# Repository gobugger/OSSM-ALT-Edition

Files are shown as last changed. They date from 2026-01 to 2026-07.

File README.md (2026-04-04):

# OSSM ALT Edition
---
## 🎯 Overview

OSSM ALT Edition is a community-driven alternative version of the well-known [OSSM](https://github.com/KinkyMakers/OSSM-hardware) platform. A lot of time and effort has gone into this project. This has been possible thanks to all the previous work that has been done and several community members that helped test this. Do note that we are still in 'beta testing' phase and that you may run into issues. Please provide feedback to help improve the project. This project represents a ground-up redesign focused on:

- **Modern Power Delivery**: Custom 28V 140W USB-C PCB with comprehensive protection circuits
- **Simplified Assembly**: All-in-one clean design with easily sourceable components
- **European Sourcing**: BOM optimized for availability in Europe
- **Enhanced Performance**: Support for MGN12H and MGN15H rails with support for belts up to 15mm belt.
- **Open Source**: Fully open hardware

***Links***: KM [Discord community](https://kinkymakers.com) & [Ko-Fi](https://ko-fi.com/dododesigns) (for contributions / buying boards)

MGN15H version with new clamp

<sub>**Notice**: This version was developed without any involvement of the original OSSM / Research and Desire members. However, none of this would have been possible without their prior work which is greatly appreciated. Especially the work of [ArmpitMFG](https://github.com/armpitMFG) has been a great inspiration. </sub>

---

## ✨ Key Features

### Hardware Improvements
- **Custom 28V USB-C PCB** with extensive protection circuits
  - Over/under voltage protection
  - Reverse current protection
  - ESD protection on all exposed ports
  - Inrush current limiting
  - Hybrid polymer capacitors for stable power
  - Brake Chopper Add-On 360Watt
- **Dual Rail Options**
  - MGN15H for heavy-duty applications (up to 15mm belts)
  - MGN12H for lighter builds (up to 12mm belts)
- **Efficient Travel**: Rail length minus 150mm usable stroke
- **Compatible with Pitclamp Mini** and includes optimized alternative design with dowels

### Electronics & Firmware
- **ESP32-S3** microcontroller with integrated RS485 controller
- **WS2812 Status LED** (firmware support pending)
- **Made for [OSSM Rust](https://github.com/orange-gem/ossm-rs)** firmware
- Compatible with step/dir control for original firmware adaptation
- **Optional Brake Chopper PCB** for enhanced safety

### Design Philosophy
- Optimized for 3D printing (minimal supports required)
- Common, easily sourceable components
- Clean, simple assembly
- Comprehensive protection systems

---
  
## 📦 Bill of Materials

A comprehensive BOM with descriptions and links can be found [here](Assembly-Info/BOM-OSSM-ALT.csv). However, the parts below are a quick summary everything you need for building this complete version:

| **Part** | **Description** | **Costs** |
| --- | --- | ----- |
| 57AIM30 | Motor | €110  |
| MGN15H Rail | Rail 40cm | €25 |
| Or MGN12H Rail | Rail 40cm | €21 |
| 625RS Bearing  | Belt Bearings | €15 |
| M5 Bolts | Complete kit | €12 |
| M3 Bolts | Complete kit | €12 |
| Dowel Pins | Precision pins | €10 |
| GT2 Belt | 50cm | €15 |
| GT2 20T pulley | 15mm | €10 | 
| Filament  | Max 500g | €20 |
| OSSM ALT 28V PCB | Designs available for self-sourcing or buy through me to support this project. | €40 |
| **Total** | Rough approximation. Check BOM for details. | €270  |

📋 **[Complete BOM with part numbers and links](Assembly-Info/BOM-OSSM-ALT.csv)**

> **Note**: You will also need a remote control device. Compatible options include:
> - Official R&D remote
> - iOS/Android apps
> - Web control interface
> - M5 Remote (check firmware compatibility)

---

## 3D Printing Tips

500 grams of filament should be enough to complete the whole build including the main pitclamp (350 without). It is optimized as much as possible for 3D printing with only 1 part requiring a small amount of supports. The filament type should not matter for most standard build, but heavy users might want to rely on something sturdier like tough-PLA, PET-G, ASA or PC. The test builds have been printed with standard Bambulab basic PLA (Not matte/silk). 

**Filament Required**: ~500g for complete build including Pitclamp

**Recommended Materials**:
- **Standard Use**: PLA, PLA+
- **Heavy Use**: Tough-PLA, PETG, ASA, PC

**Important**: Follow the [detailed 3D printing guide](Assembly-Info/Print-Manual/README.md) carefully to ensure proper fit and function.

**Print Options**:
- Standard version (no branding)
- Multi-color branded version (AMS/toolchanger compatible)
- Single-color embossed version

MGN12H Light version

---
## Assembly:

📺 **Video Assembly Guides**:
- [Part 1](https://youtu.be/EqzNXQzpHu0) 
- [Part 2](https://youtu.be/FnY4Sz64H2A) 

📖 **Written Assembly Guide**: In development

💬 **Need Help?** Join the KM [Discord community](https://kinkymakers.com) for assembly support and questions (Look for the OSSM ALT Project).

---

## 🔌 Main PCB Specifications

Most work has gone into this PCB. My vision for this Machine/PCB is that groups of people will self-source this PCB. From 10+ pieces this makes sense, so as long as you can find 10 people you should be able to buy this at an affordable price. The rest of the machine can be printed and uses off the shelf parts. I will also sell these boards for people that only need 1 PCB and want to help support this project (please not that a lot of my own money has gone into this and any support is greatly appreciated ([Ko-Fi](https://ko-fi.com/dododesigns))

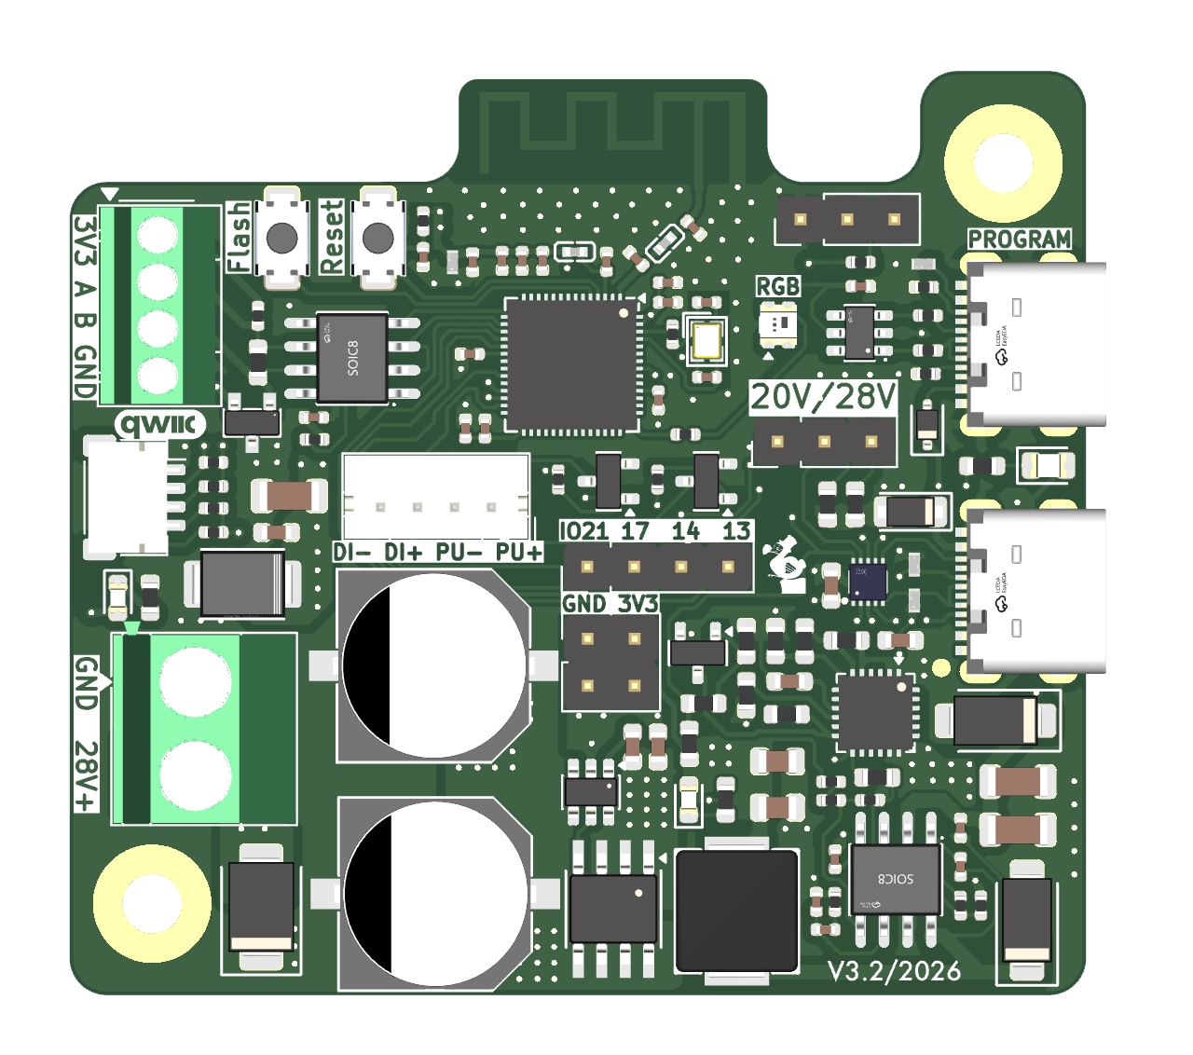
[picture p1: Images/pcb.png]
28V PCB


### Technical Features

- **Power**: CH224Q for 28V USB-C PD 3.2 negotiation
- - Continuous 140Watt capable with 4 layer optimized PCB design (load tested)
- **Controller**: ESP32-S3 microcontroller with onboard antenna
- **Communication**: Integrated RS485 controller
- **Power Protection**:
  - Hybrid polymer capacitors
  - Inrush current limiting
  - Over/under voltage protection
  - Reverse current protection
- **Additional Features**:
  - Dedicated USB-C debugging port
  - ESD protection on all exposed ports
  - WS2812 status LED
  - Brake chopper expansion support

**Design Tool**: KiCAD 9  
**Manufacturing**: Optimized for major PCB fabrication houses

### Optional Brake Chopper Add-on

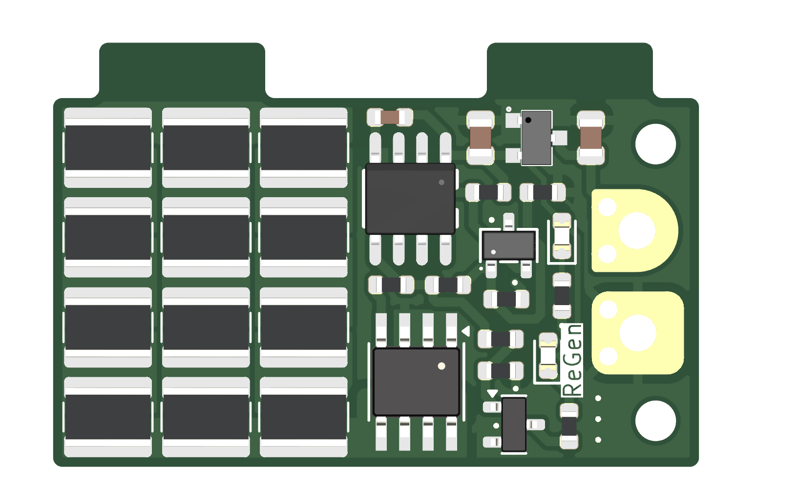
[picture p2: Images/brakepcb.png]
Brake PCB


Enhanced protection for heavy-duty use:
- **Dissipation**: 12W continuous, 360W short-term spikes
- **Protection Threshold**: 33V (protects 36V TVS diode)
- **Purpose**: Back-EMF spike suppression
- **Recommended For**: Heavy users and added safety margin

This was mainly a fun side project for me which also adds functionality. It is basically an improved version of a Pololu Shunt Regulator, but completely redesigned with an on-board gate driver, 12V LDO, and 12watts of power resistors (2 sides assembly up to 24watt). This PCB was designed to be very cheap and easy to produce. 

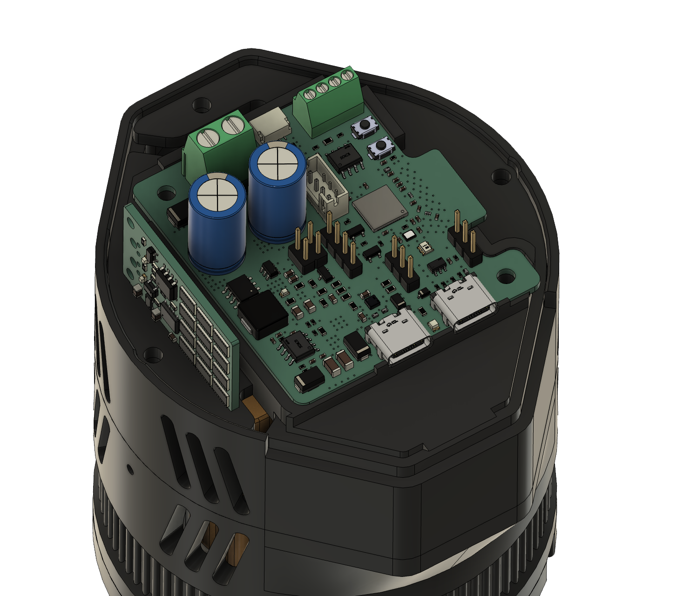
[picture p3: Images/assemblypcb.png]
Assembly PCB


---
## 🔋 Compatible Power Sources

This design is focused around PD, so it only makes sense to provide some options that are tested.

> **Important**: Use a USB-C cable with E-marker chip for >3A current. Standard cables will limit performance.

### Tested & Confirmed

| Device | Type | Rating | Status | Recommended | Rating | Notes |
|---|---|---|---|---|---|-----|
| [Apple 140W USB-C Adapter](https://www.apple.com/nl/shop/product/mw2m3zm/a/usb%E2%80%91c-lichtnetadapter-van-140-w) | Wall Adapter | 28V / 5A (140W) | 🔬 Tested | ✅ Recommended| ★★★★★ (5)| Excellent reliability and quality, Only ~€60 (will likely not work with other pcb's besides the OSSM ALT since it requires inrush current protection) |
| [Ugreen 200W Powerbank](https://eu.ugreen.com/products/ugreen-nexode-power-bank-200w-25000mah) | Powerbank | 28V / 5A (140W) | 🔬 Tested| ✅ Recommended|★★★★★ (5)| Great portable option that negotiates with almost any chip. Best power bank I have tested.|
| [Anker 140W Wall Adapter](https://www.anker.com/products/a2697-anker-charger-140w-4-port) | Wall Adapter | 28V / 5A (140W) | 🔬 Tested| ✅ Recommended|★★★★☆ (4)| Works well, but you will definitely feel it get hot at prolonged 140W and after 20 minutes or so it will lower the power to cool down. 100Watts continuous is fine so for the gold motor there are no problems. I have yet to see a supported motor that pulls 140W continuous. 
| [Sitecom 140W Wall adapter](https://www.action.com/nl-nl/p/3221194/sitecom-usb-wandoplader/) | Wall Adapter | 28V / 5A (140W)|🔬 Tested | ✅ Recommended| ★★★★☆ (4) | Cheapest adapter of the list (~€20). Did not do any extensive testing yet, but it negotiates 28V and 20V fine. I was also able to load test it at 140W and you can feel it get warmer similar to the Anker one, but it seems to hold up fine. At it's price point it is probably a very good deal (even comes with a cable), but we don't know if it's easy to source since right now it's sold at 'action' which normally changes its inventory quite quickly. 
| [Ugreen 100W Wall Adapter](https://www.amazon.nl/dp/B091TV6LWN) | Wall Adapter | 20V / 5A (100W) | 🔬 Tested | ⚠️ Lower Power|★★★☆☆ (3) |Works okay, but do notice that this one does not support 28V. If you have the OSSM-Alt pcb at 28V and still try to power it, it will work but negotiates down to 20V. |
| [Framework 180W Adapter](https://frame.work/nl/en/products/16-power-adapter?v=FRANCR000F) | Wall Adapter | 36V / 5A (180W) | 🔬 Tested | ⚠️ Lower Power | ★★★☆☆ (3) | Quality wise I believe this is a good adapter, but it has a lot of difficulty negotiating with several common cheap PD chips. So it won't negotiate above 20V on the OSSM-ALT PCB and it also does not seem to support I2C with this chip either. Therefore, not really recommended unless you already have it and just power a motor at max 100W. 
| Apple 67W Adapter | Powerbank | 20V / 3.3A (67W) | 🔬 Tested | ⚠️ Lower Power | ★★☆☆☆ (2.5) | Negotiates well and also supports I2C negotiation. 67W is however on the lower side, so this is definitely not recommended for heavy usage. Still, this was the adapter I first tested my OSSM with and from my experience 67W is enough for most light play.  |
| Xiaomi Mi 50W | Powerbank | 20V / 2A (40W) | 🔬 Tested | ⚠️ Low Power | ★★☆☆☆ (2) | Not recommended. Negotiates well, but low power. Still for a very light weight OSSM it might. be fine.  |

**Have you tested another power source?** Please share your results!

---

## ❤️ Support the Project

If you've built an OSSM ALT and want to support continued development:

### Financial Support

- **PCB Purchase**: Buy boards from me to support the project (Discord PM, Ko-Fi (soon))
- **Buy a hardware kit**: If there is enough demand, I might start selling some hardware kits 
- **Donations**: [Ko-Fi](https://ko-fi.com/dododesigns) *(or contact me on Discord)*

### Non-Financial Support

- ⭐ **Star this repository** to increase visibility
- 📢 **Share the project** with your community
- 📸 **Share your build** with photos and feedback on Discord
- 📖 **Contribute documentation** and improvements

teaser

---

## 📜 License

This project is **Open Source Hardware**.

All hardware design files (including PCB schematics, layouts, and 3D mechanical design files) are licensed under the **CERN Open Hardware Licence Version 2 – Strongly Reciprocal (CERN-OHL-S-2.0)**.

You are free to:
- Use, study, modify, and manufacture this design

Under the following conditions:
- **Attribution** must be given to the original author(s)
- **All modified versions and derivatives must be released under the same license**
- **Complete corresponding source files must be made available**

---

## 🙏 Acknowledgments

Special thanks to:

### Core Contributors
- **OrangeMurker & Nakata** - OSSM Rust firmware development and invaluable feedback
- **Beta Testers** - All community members who tested and provided feedback

### Inspiration & Prior Art
- **[armpitMFG](https://github.com/armpitMFG)** - Front/end effector designs and Pitclamp Mini
- **Original OSSM / R&D Team** - Foundation and inspiration for this project

### Community
- All contributors who have improved this design
- Discord community members providing support and feedback

---

## ⚠️ Disclaimer

This project is currently in **beta testing phase**. While extensively tested, you may encounter issues. Please provide feedback to help improve the project.

**Safety**: This is a DIY project involving motors and electronics. Build and use at your own risk. Ensure all safety precautions are followed during assembly and operation.

---

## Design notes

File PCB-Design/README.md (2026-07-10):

# PCB Design

This folder contains everything related to the two PCBs of the OSSM ALT Edition (the main PCB and the brake chopper), organized as follows:

| Folder | Contents |
| --- | --- |
| [Schematic and Design](Schematic%20and%20Design/) | The schematics of both PCBs and their STEP files |
| [Production Files](Production%20Files/) | A manual on ordering, plus all the files needed to produce the PCBs yourself (Gerbers, BOM, CPL) |
| [Kicad Files](Kicad%20Files/) | The KiCad project files, if you wish to edit things |

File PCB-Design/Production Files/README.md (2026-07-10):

# Production Files

This folder contains everything you need to order the PCBs and cables for the OSSM ALT Edition. There are **two separate boards** plus the **cables**:

| Item | Location | Status |
| ---- | --- | --- |
| **Main PCB** (OSSM ALT Servo) | [Main-PCB](Main-PCB/) | ✅ Production ready |
| **Brake Chopper** (optional add-on) | [Brakechopper](Brakechopper/) | ✅ Production ready |
| **Cables** (power & RS485) | [Cable Sourcing](#-cable-sourcing) (below) | ✅ Production ready |

Each version folder contains the Gerber files (zip), BOM and CPL (component placement) files, ready for upload.

---

## 🟢 Main PCB

The main PCB is best ordered from **[JLCPCB](https://jlcpcb.com)**. All components have been selected based on availability from LCSC and compatibility with JLCPCB's **Economic Assembly** service, which saves quite a bit on setup costs compared to Standard assembly.

### PCB Specifications

These are basically the default JLCPCB settings for a 4-layer board, to keep ordering easy. They are written out here in case you use another PCB supplier:

| Setting | Value |
| --- | ----- |
| Layers | 4 |
| Thickness | 1.6mm |
| Material | Standard FR4, **TG135** |
| Stackup | "No requirement" — currently **JLC04161H-7628** (the default for 4-layer 1.6mm) |
| Outer copper | 1oz |
| Inner copper | 0.5oz |
| Surface finish | HASL — ENIG is nicer/better, but on a 4-layer board it is not supported with Economic Assembly, only Standard |

> ⚠️ **Important**: The material and stackup matter for impedance matching. The WiFi antenna is calculated based on the JLC04161H-7628 stackup (the one JLCPCB selects by default when you choose "no requirement" on a 4-layer 1.6mm board). If you order elsewhere, match this stackup as closely as possible.

### Assembly Settings

- Select **PCB Assembly**, **top side** only.
- Choose the **Economic** assembly type. All parts have been sourced to be compatible with it.

> 💡 **Tip — parts out of stock?** The hard part of ordering via Economic Assembly is that not all parts are always in stock. Have a look at JLCPCB's **Part Sourcing** section on their website: you can pre-order parts beforehand at very affordable prices and build your own personal inventory. Once everything is in your personal stock, you can place the assembly order.

### Parts You Solder Yourself

To save costs, the through-hole headers and the back-emf capacitors are **not** pre-soldered. These are easy through-hole parts you can solder at home:

| Qty | Part | LCSC # | Purpose |
| --- | ---- | --- | --- |
| 2 | 1x3 pin header, 2.54mm | [C32713269](https://jlcpcb.com/partdetail/C32713269) | Voltage selection & IO |
| 1 | 2.54mm jumper | [C20417895](https://jlcpcb.com/partdetail/C20417895) | Voltage selection (20V/28V) |
| 1 | JST PH 1x4 connector | [C131334](https://jlcpcb.com/partdetail/C131334) | RS485 cable connection |
| 1 | *(alternative)* 4-position 2.54mm terminal connector | [C918122](https://jlcpcb.com/partdetail/C918122) | Use instead of the JST PH if you don't want to crimp a custom cable |
| 1 | 2-position 5.08mm power terminal | [C8465](https://jlcpcb.com/partdetail/C8465) | 28V power input |
| 2 | 470µF 50V hybrid polymer capacitor | [C53237827](https://jlcpcb.com/partdetail/C53237827) | Catches back-EMF spikes |

### About the Capacitors (Back-EMF)

The two 470µF 50V hybrid polymer capacitors are **very important if you don't use a brake chopper** — they catch the back-EMF spikes from the motor. With the brake chopper installed you could get away with a smaller SMD variant.

You can also choose 35V versions, which are available at 1000µF each (2000µF total). For smaller/regular sized toys this would be safe enough to run without a brake chopper. **However**, under heavy usage with very fast back pressure, the voltage can rise to around **43V** with 1000µF of capacitance — above the 35V rating. With 2000µF it would stay lower, but this is **not recommended and not tested**. When in doubt, stick with the 50V parts.

### Polarity Checks (Important!)

JLCPCB will probably send you an email asking to **confirm the orientation of the WS2812 RGB LED** — for some reason they keep doing that with this specific part. Just confirm the polarity matches the image below and continue:

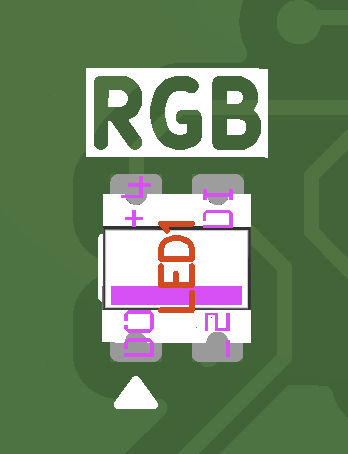
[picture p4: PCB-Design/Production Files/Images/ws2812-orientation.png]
WS2812 orientation


Also check all other polarities (diodes, polarized capacitors). If you use the **provided CPL file, it should be fine** — but a fresh export from KiCad will probably *not* have the right rotations, and you will need to check them yourself. Use this overview of the fully placed top side as reference:

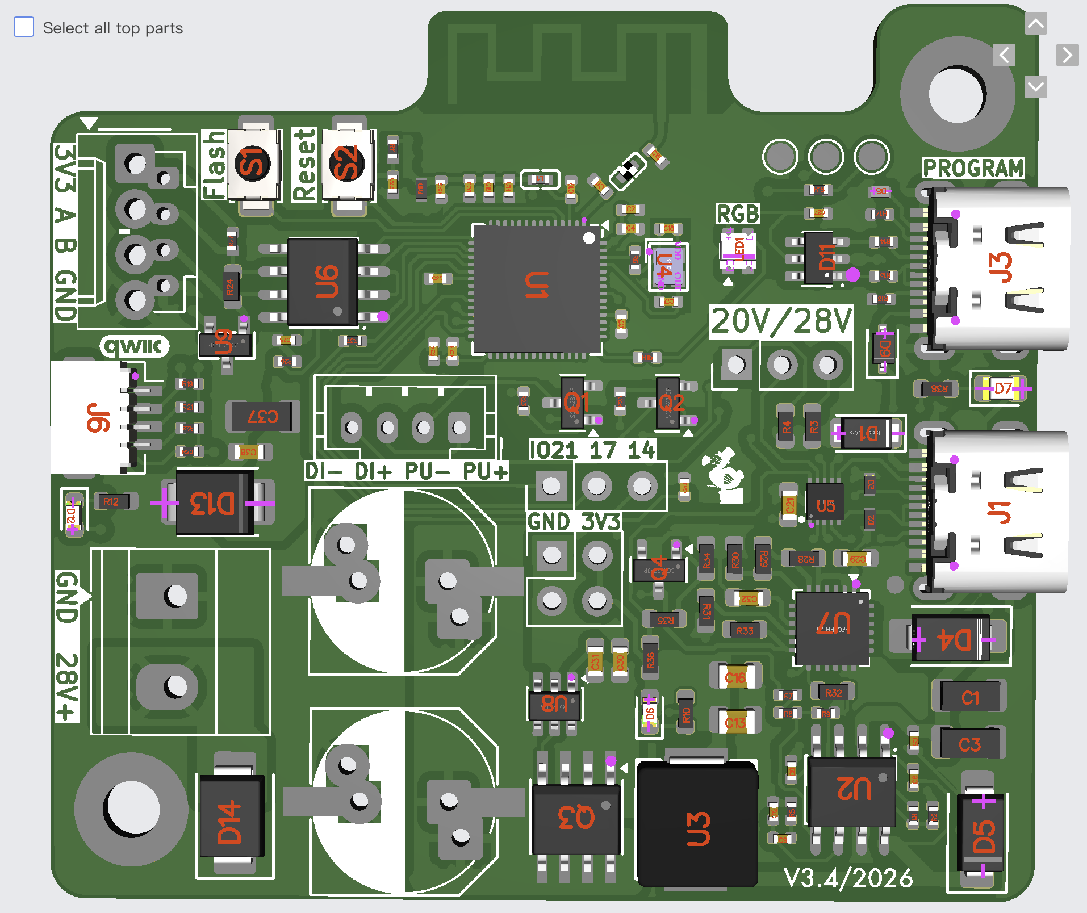
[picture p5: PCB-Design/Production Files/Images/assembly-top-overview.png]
Top side assembly overview


---

## 🟡 Brake Chopper

The brake chopper is an optional add-on designed as **extra protection for the main PCB**. It catches the voltage spikes from the motor that happen when the motor rapidly decelerates, changes direction, or is pushed back. This has been thoroughly tested: it stops all spikes over **33V**, which then get dumped into the 1218 resistor bank.

The production files can be found in [Brakechopper/v1_1](Brakechopper/v1_1/).

### PCB Specifications

| Setting | Value |
| --- | ----- |
| Layers | 2 |
| Copper | 1oz |
| Surface finish | ENIG or HASL (both will work) |

### Single or Double Sided Assembly

You can choose to have this board assembled **one sided or double sided** — both will work, but the power dissipation rating of the resistor bank differs:

| Assembly | Resistors | Power dissipation rating |
| --- | --- | --- |
| Double sided | 24 | 24W |
| Single sided | 12 | 12W |

> **Note**: this is *not* a continuous rating — the board is not designed to draw power continuously. It only dissipates the short braking spikes.

It's a clean design that you should be able to source at very low cost: the first single-sided version came out at roughly €1.50 each assembled, and the double-sided version at around €5. Both will probably be pricier at lower quantities.

### Sourcing the Resistors (the hard part)

The tricky part is sourcing the resistors in larger quantities: 10 boards is already 240 resistors, and 100 boards means finding 2400 of them. JLCPCB can ask extreme prices for ordering these reels, so it makes more sense to **pick a resistor value that is in stock / affordable to source** rather than insisting on one exact value.

The reference design uses **4.7Ω** resistors. On the double-sided board the bank is wired as: top+bottom pairs in parallel (4.7Ω / 2 = 2.35Ω), 4 of those in series (9.4Ω), and 3 of those columns in parallel — giving a total resistance of:

```
(4.7Ω / 2) × 4 / 3 ≈ 3.13Ω
```

At the 33V clamping point that dissipates **P = V² / R = 33² / 3.13 ≈ 348W** (about 10.5A) during a braking event.

For a **single-sided** board there are no parallel pairs, so the total is simply `value × 4 / 3`. With only 12 resistors, a value of around **2.4Ω** makes more sense:

```
2.4Ω × 4 / 3 = 3.2Ω  →  33² / 3.2 ≈ 340W
```

> ⚠️ **Rule of thumb**: aim for roughly **3.1–3.2Ω total resistance (~350W dissipation)**. I would not go higher than this — a too high total resistance lowers the spikes the board can catch which means that these spikes then still go to the main board.

### Status LEDs

The board has two LEDs:

- 🟠 **Orange** — the board has power.
- 🔴 **Red** — the voltage has risen above 33V and the brake chopper is actively dumping into the resistor bank.

### Polarity Checks

Just like the main PCB: check the component polarities against the provided images before confirming the order.

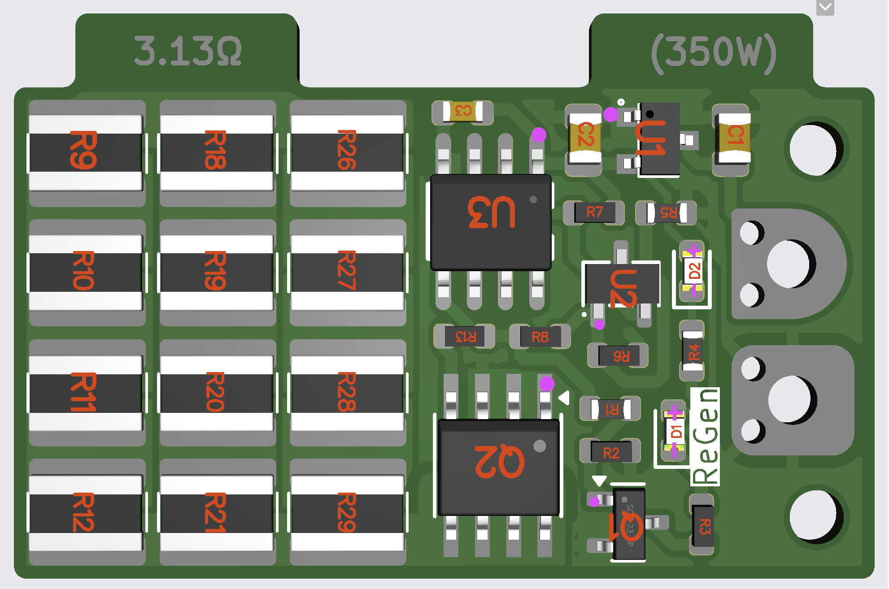
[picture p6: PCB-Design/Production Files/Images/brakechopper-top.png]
Brake chopper top side


---

## 🔌 Cable Sourcing

### Main Power

For the main power supply to the board I use **18 AWG silicone cables**. These silicone cables are nice and flexible and can easily handle the currents.

### RS485 Cable

For the RS485 connection between the board and the motor there are two options:

1. **Terminal block** — use the 4-position terminal connector ([C918122](https://jlcpcb.com/partdetail/C918122), see the main PCB parts table), cut the connector off one side of the cable that came with the motor, and hook it up that way.
2. **Custom RS485 cable** — this is what the boards I sold use. It's more foolproof and easier to assemble/disassemble.

For the custom cable I used **LCSC's cable assembly service**. To give an idea of pricing: 50 pieces cost around **€85 including shipping** — it probably makes more sense at higher quantities. At lower quantities you should be able to crimp them yourself with the parts below.

The cable specs: roughly **70mm long**, **24 AWG silicone wire**, with the data pair twisted (**~6 twists**). Twisting shouldn't be necessary at this short length, but it's basically free when ordering through LCSC.

> **Note**: I can't share the original manufacturer drawing (I don't hold the copyright), so the drawing below is a recreation with the same information.

RS485 cable drawing

Wiring table (also shown in the drawing — the used pins are colored in the P1 mating face view):

| Wire | P1 pin | P2 pin |
| ----- | --- | --- |
| Green | 7 | 2 |
| Blue | 8 | 3 |
| Red | 5 | 1 |
| Black | 1 | 4 |

The numbered callouts in the drawing match this parts list:

| # | Part | Qty | Description | LCSC # |
| - | ---- | --- | --- | --- |
| 1 | Wire | 4 | UL1007 24 AWG (red / blue / green / black), L = 70mm | — |
| 2 | Housing | 1 | 2.0mm pitch, 2×5 positions, white — Megastar ZX-PHB2.0-2-5PJK | [C19078773](https://www.lcsc.com/product-detail/C19078773.html) |
| 3 | Terminal | 4 | Tin plated, 24–28 AWG — Megastar ZX-PHB2.0-2-DZ | [C19078769](https://www.lcsc.com/product-detail/C19078769.html) |
| 4 | Housing | 1 | 2.0mm pitch, 4 positions, white — JST PHR-4 | [C111514](https://www.lcsc.com/product-detail/C111514.html) |
| 5 | Terminal | 4 | Tin plated, 22–26 AWG — JST SPH-001T-P0.5S | [C495193](https://www.lcsc.com/product-detail/C495193.html) |

To clarify, here are photos of a finished cable and close-ups of both connector ends:

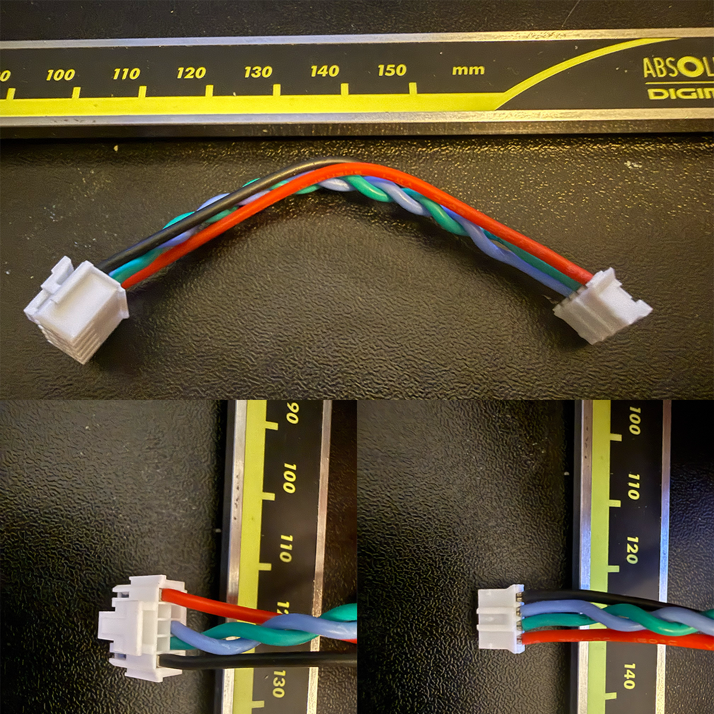
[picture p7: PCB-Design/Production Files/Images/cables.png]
Finished RS485 cable


---

## ⚠️ Disclaimer

No warranties are given based on the information in this document. Ordering PCBs and cables is always a risk, and I take no responsibility for the correctness of this information. Previous experience with ordering PCB assembly definitely helps — these are not the easiest boards.

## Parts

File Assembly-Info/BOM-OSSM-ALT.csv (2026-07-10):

Assembly Category,Item No.,Part Name,Description,Quantity,Unit,Supplier Link,Unit Price,Total Price,Remarks
"Belt Mechanics,B-0,MGN-15H Rail,""Tested with 400mm Length"",1,pcs,,,,""The better the quality, the smoother it will be. Legitimate Hiwin is preferred, but Aliexpress alternatives will probably work as well. Usable length is approximately rail length - 150mm"""
"Belt Mechanics,B-1,625-RS Bearings,Belt Bearings,6,pcs,https://www.amazon.nl/dp/B071RXC7FV?,€8.99,€8.99,""10 Pack"""
"Belt Mechanics,B-2,Precision Dowel Pin Kit,Dowel Pins for Bearings Kit,1,pcs,https://www.amazon.nl/dp/B0DR7R87KQ?th=1,€12.99,€12.99,""This pack contains all the pins needed for the complete OSSM ALT version including new Pit Clamp"""
"Belt Mechanics,B-2B,M5*30 Dowel Pin (2 pins),M5*30 dowel 5 pack,1,pcs,https://eu.store.bambulab.com/nl/products/d5-stainless-steel-dowel-pin?id=48706172092764,€1.45,€1.45,""This is sufficient if you are only making the belt mechanics without redesigned pitclamp. You do not need the dowel pin kit in this case"""
"Belt Mechanics,B-3,GT2 Belt (9-12 or 15mm),""Rail length + 10cm"",,,,,,""Pick any GT2 belt that will fit your GT2 pulley. OSSM ALT version supports everything up to 15mm. 15mm gives the most grip"""
"Belt Mechanics,B-4,GT2 20T Pulley (15mm belt max),Pulley for your belt size,1,pcs,,,,""Pick a pulley that fits your belt. A pulley that supports a 15mm belt has maximum performance, but 9 or 12mm will work as well"""
"Belt Mechanics,B-5,M5 Bolt Kit,M5 bolt kit for complete OSSM ALT,1,pcs,https://www.amazon.nl/dp/B0DPWYNDZF?,€11.99,€11.99,""This kit contains all the M5 bolts that are needed for the complete OSSM Alt Edition including redesigned Pitclamp"""
"Belt Mechanics,B-5B,M5*30 Head Cap Bolt,Front mount bolts,2,pcs,,,,""Only needed if you don't buy the M5 bolt kit"""
"Belt Mechanics,B-5C,M5*20 Head Cap Bolt,Front mount bolts,1,pcs,,,,""Only needed if you don't buy the M5 bolt kit"""
"Belt Mechanics,B-6,M3 Bolt Kit,M3 bolt kit for complete OSSM ALT,1,pcs,https://www.amazon.nl/dp/B0B3MGZ7T2,€8.88,€8.88,""This kit contains all the M3 bolts that are needed for the complete OSSM Alt Edition"""
"Motor / PCB Housing,C-0,57AIM30 motor,OSSM Motor,1pcs,,,€100,,""Around 100 euros including shipping and taxes to Europe"""
"Motor / PCB Housing,C-1,M3 Bolt Kit,M3 bolt kit for complete OSSM ALT,1,pcs,https://www.amazon.nl/dp/B0B3MGZ7T2,€8.88,€8.88,""This kit contains all the M3 bolts that are needed for the complete OSSM Alt Edition"""
"Belt Mechanics,B-6B,M3*12 Head Cap Bolt,Rail bolts,4,pcs,,,,""Only needed if you don't buy the M3 bolt kit"""
"Motor / PCB Housing,C-1B,M3*40 bolt,Housing bolts,2,pcs,,,,""Only needed if you don't buy the M3 bolt kit"""
"Motor / PCB Housing,C-1C,M3*8 bolt,PCB Mount,2,pcs,,,,""Only needed if you don't buy the M3 bolt kit"""
"Motor / PCB Housing,C-1D,M3*12 bolt,Top Cover Bolt,1,pcs,,,,""Only needed if you don't buy the M3 bolt kit"""
"Motor / PCB Housing,C-2,M5*30 bolt,Motor Fastening Bolts,4,pcs,,,,""Only needed if you don't buy the M5 bolt kit (also not needed if you are using the original OSSM belt mechanics/front)"""
"Motor / PCB Housing,C-1E,M3 nuts,Captive Nuts,5,pcs,,,,""Only needed if you don't buy the M3 bolt kit"""
"Motor / PCB Housing,C-2B,M5 nuts,Captive Nuts,3,pcs,,,,""Only needed if you don't buy the M5 bolt kit"""
"Motor / PCB Housing,C-2C,M5 Lock nuts,M5 Motor lock nuts,4,pcs,https://www.toolstation.nl/borgmoeren/p12051,€3.05,€3.05,""You can also use regular nuts, but those might vibrate. This is also needed if you are using the original OSSM. The link is for 100 pieces"""
"Motor / PCB Housing,C-3,OSSM ALT version Custom PCB,Custom PCB for the ALT Version,1,pcs,,TBD,TBD,""All production files are available. If you source them yourself and order a minimum of 10, the price should drop to around 13 euros per piece, and to 10 euros at 20+"""
"Redesigned Pitclamp,D-1,Precision Dowel Pin Kit,Dowel Pins for Bearings Kit,1,pcs,https://www.amazon.nl/dp/B0DR7R87KQ?th=1,€12.99,€12.99,""This pack contains all the pins needed for the complete OSSM ALT version including new Pit Clamp"""
"Redesigned Pitclamp,D-1B,M5*25 Dowel Pin (3 pins),M5*25 dowel 5 pack,1,pcs,https://eu.store.bambulab.com/nl/products/d5-stainless-steel-dowel-pin?id=48706172059996,€1.45,€1.45,""Only needed if you don't buy the dowel pin kit"""
"Redesigned Pitclamp,D-1B,M5*16 Dowel Pin (1 pins),M5*16 dowel 5 pack,1,pcs,https://eu.store.bambulab.com/nl/products/d5-stainless-steel-dowel-pin?id=48706171994460,€1.35,€1.35,""Only needed if you don't buy the dowel pin kit"""
"Redesigned Pitclamp,D-2,M5*20 Head Cap bolt,Bolts to mount to 3030 extrusion,2,pcs,,,,""Only needed if you don't buy the M5 bolt kit"""
"Redesigned Pitclamp,D-2,3030 extrusion M5 fastening nuts,M5 nuts for 3030 extrusion,2,pcs,,,,""Just pick what you have or what you can get. As long as it's M5 and fits 3030, it will work"""
Belt Clamp,E-1,M3 nuts,M3 nut,1,pcs,,,,
"Belt Clamp,E-2,M3*16 head cap bolt,Optional for front mount,1,pcs,,,,""Optional to make sure it stays on, but not necessary since everything is tightened together by the belt"""
"Other,F-0,3D print filament,""500g should be more than sufficient."",,,,,,""Pitclamp: 100g / Belt tensioning and toy mount: 63g / Belt mechanics: 117g / Main mechanics: 162g. Total: 442g"""

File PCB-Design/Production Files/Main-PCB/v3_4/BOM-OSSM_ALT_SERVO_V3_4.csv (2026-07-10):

Comment | Designator | Footprint | LCSC | Quantity
0Ω | R6,R7 | R_0402 | C17168 | 2
1.5kΩ | R37,R9 | R_0402 | C25867 | 2
1.5pF | C11,C15 | C_0402 | C1552 | 2
100nF | C30,C31,C32,C38 | C_0603 | C14663 | 4
100nF | C10,C14,C23,C25,C7 | C_0402 | C1525 | 5
100nF | C27,C28,C6 | C_0402 | C307331 | 3
100Ω | R21,R22 | R_0402 | C25076 | 2
10kΩ | R11 | R_0402 | C25744 | 1
10kΩ | R33,R36 | R_0603 | C25804 | 2
10nF | C4,C5,C8 | C_0402 | C15195 | 3
10uF | C37 | C_1206 | C13585 | 1
10uF | C20,C26 | C_0402 | C15525 | 2
120kΩ | R4 | R_0603 | C25808 | 1
120Ω | R24 | R_0603 | C22787 | 1
13kΩ | R29 | R_0603 | C22797 | 1
150kΩ | R1 | R_0402 | C25755 | 1
15pF | C17,C18 | C_0402 | C1548 | 2
1nF | C39,C9 | C_0402 | C1523 | 2
1uF | C21,C29 | C_0603 | C15849 | 2
1uF | C19,C2,C22,C24 | C_0402 | C52923 | 4
2.0nH | L1 | L0402 | C18216 | 1
2.7nH | L2 | L0402 | C778766 | 1
20kΩ | R12,R30,R32,R38 | R_0603 | C4184 | 4
210kΩ | R3 | R_0603 | C22952 | 1
3.3kΩ | R31 | R_0603 | C22978 | 1
30kΩ | R5 | R_0402 | C25553 | 1
330Ω | R15 | R_0402 | C25104 | 1
33Ω | R13,R14 | R_0402 | C25105 | 2
4.7kΩ | R19,R20,R26,R27,R8 | R_0402 | C25900 | 5
4.7uF | C1,C3 | C_1206 | C29823 | 2
40Mhz | U4 | ESP32 40Mhz Crystal C7206306 | C7206306 | 1
470kΩ | R28,R34 | R_0603 | C23178 | 2
470Ω | R18,R23,R25 | R_0402 | C25117 | 3
47kΩ | R35 | R_0603 | C25819 | 1
47pF | C12 | C_0402 | C1567 | 1
47uF | C13,C16 | C_0805 | C16780 | 2
5.1kΩ | R16,R17 | R_0402 | C25905 | 2
510Ω | R10 | R_0603 | C23193 | 1
68kΩ | R2 | R_0402 | C36871 | 1
B0540WS | D9 | D_SOD-323 | C7420326 | 1
BC817-25 | Q1,Q2,Q4 | Q_SOT-23 | C20069154 | 3
CH224Q | U5 | SON-10_L2.0-W2.0-P0.40-TL-EP | C46061833 | 1
CYA0630-6.8UH | U3 | IND-SMD_L7.2-W6.6_GPSR0730 | C5189749 | 1
Conn_01x04_Socket | J6 | JST_SH_SM04B-SRSS-TB_1x04-1MP_P1.00mm_Horizontal | C51940130 | 1
Connector, USB-TYPE-C-16P | J1,J3 | TYPE-C-SMD_HX-TYPE-C-16PIN | C2927039 | 2
ES5JBF | D13 | D_SMBF | C18199154 | 1
ESP32-S3 | U1 | QFN-56-1EP_7x7mm_P0.4mm_EP4x4mm_ThermalVias | C2913196 | 1
FDS5351 | Q3 | SO-8 N-channel mosfet FDS5351 | C241809 | 1
Green | D7 | D_0805 | C2297 | 1
H5VL10BC | D10,D2,D3 | D_DFN1006-2L | C20615784 | 3
H5VU10U | D8 | D_DFN1006-2L | C22395519 | 1
LM74700 | U8 | SOT-23-6 | C2941042 | 1
Red | D12,D6 | D_0603 | C2286 | 2
SM712-02HTG | U9 | SOT-23-3_L2.9-W1.3-P1.90-LS2.4-BR | C5449363 | 1
SMBJ33CA | D14 | D_SMB | C19077587 | 1
SMF30A | D1 | D_SOD-123FL | C19077518 | 1
SP3485EN | U6 | SOIC-8_L5.0-W4.0-P1.27-LS6.0-BL | C8963 | 1
SRV05-4 | D11 | SOT-23-6_L2.9-W1.6-P0.95-LS2.8-BL-1 | C7420376 | 1
SS33 | D5 | D_SMA | C28646294 | 1
SS34 | D4 | D_SMA | C8678 | 1
TPS16630RGER | U7 | VQFN-24-1EP_4x4mm_P0.5mm_EP2.5x2.5mm_ThermalVias | C1850279 | 1
TPS54331DR | U2 | SOIC-8_L5.0-W4.0-P1.27-LS6.0-BL | C9865 | 1
Tactile Button, 160gf | S1,S2 | SW_TS-1088-AR02016 | C720477 | 2
WS2812_2020 | LED1 | LED_WS2812_2020 | C42417600 | 1

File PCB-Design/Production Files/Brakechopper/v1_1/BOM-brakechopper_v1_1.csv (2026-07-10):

Comment | Designator | Footprint | LCSC | Quantity
100kΩ | R2 | R_0603 | C25803 | 1
100nF | C3 | C_0603 | C14663 | 1
10kΩ | R1,R4,R5 | R_0603 | C25804 | 3
10uF | C1,C2 | C_0805 | C440198 | 2
10Ω | R13 | R_0603 | C22859 | 1
120kΩ | R6 | R_0603 | C25808 | 1
1MΩ | R8 | R_0603 | C22935 | 1
4.7kΩ | R3 | R_0603 | C23162 | 1
4.7Ω | R10,R11,R12,R14,R15,R16,R17,R18,R19,R20,R21,R22,R23,R24,R25,R26,R27,R28,R29,R30,R31,R32,R33,R9 | R_1218_3246Metric_Pad1.22x4.75mm_HandSolder | C876073 | 24
47kΩ | R7 | R_0603 | C25819 | 1
BC817-25 | Q1 | Q_SOT-23 | C20069154 | 1
CJ431 | U2 | SOT-23-3_L2.9-W1.6-P1.90-LS2.8-BR | C3113 | 1
EG2131 | U3 | SOP-8_L4.9-W3.9-P1.27-LS6.0-BL | C5240691 | 1
FDS5670-NL-VB | Q2 | SO-8 N-channel mosfet FDS5351 | C5878792 | 1
MD7680EC0QA3 | U1 | SOT-23-3L_L2.9-W1.6-P1.90-LS2.8-BL | C42377927 | 1
Red | D1 | D_0603 | C2286 | 1
Yellow | D2 | D_0603 | C89811 | 1

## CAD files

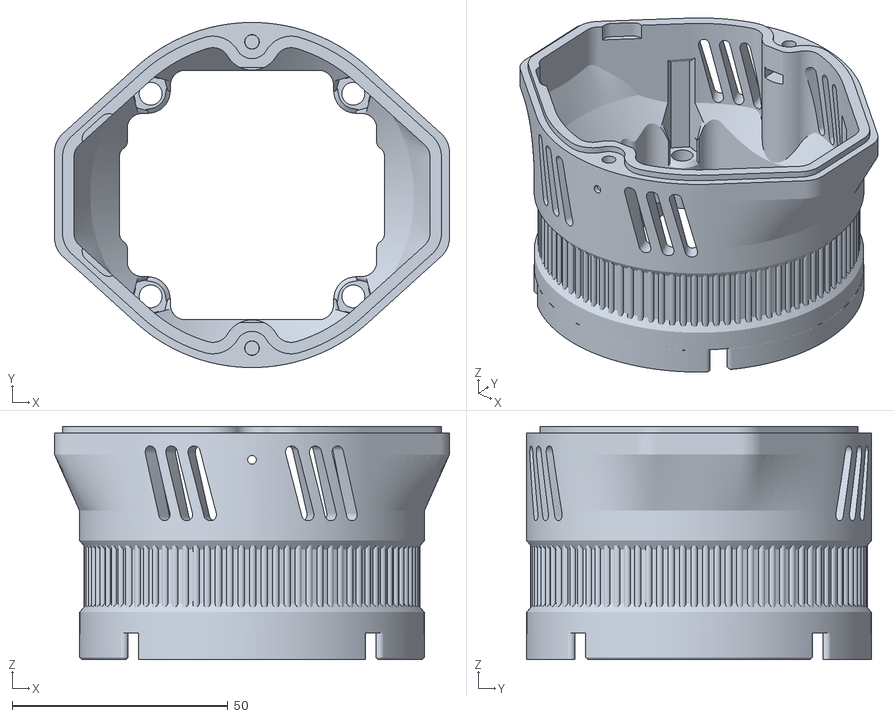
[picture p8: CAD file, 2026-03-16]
Hardware-Design/Motor and PCB Housing/STL/Motor Mount - Main Clamp.stl
91.6 x 80.0 x 54.1

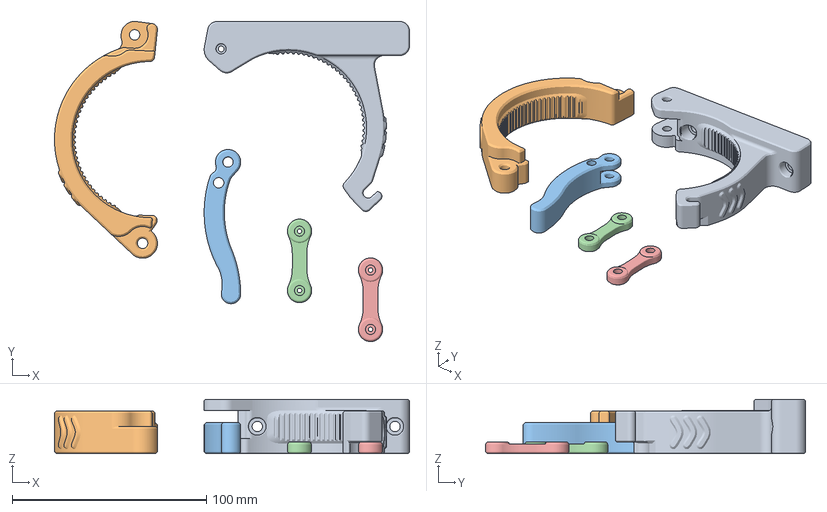
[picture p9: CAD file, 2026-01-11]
Print-Files/Alternative Pitclamp/Complete Sliced Alternative Pitclamp.3mf
182.5 x 164.6 x 28.0 mm
Lower.stl
Upper.stl
Handle.stl
Dogbone (x2).stl x 2

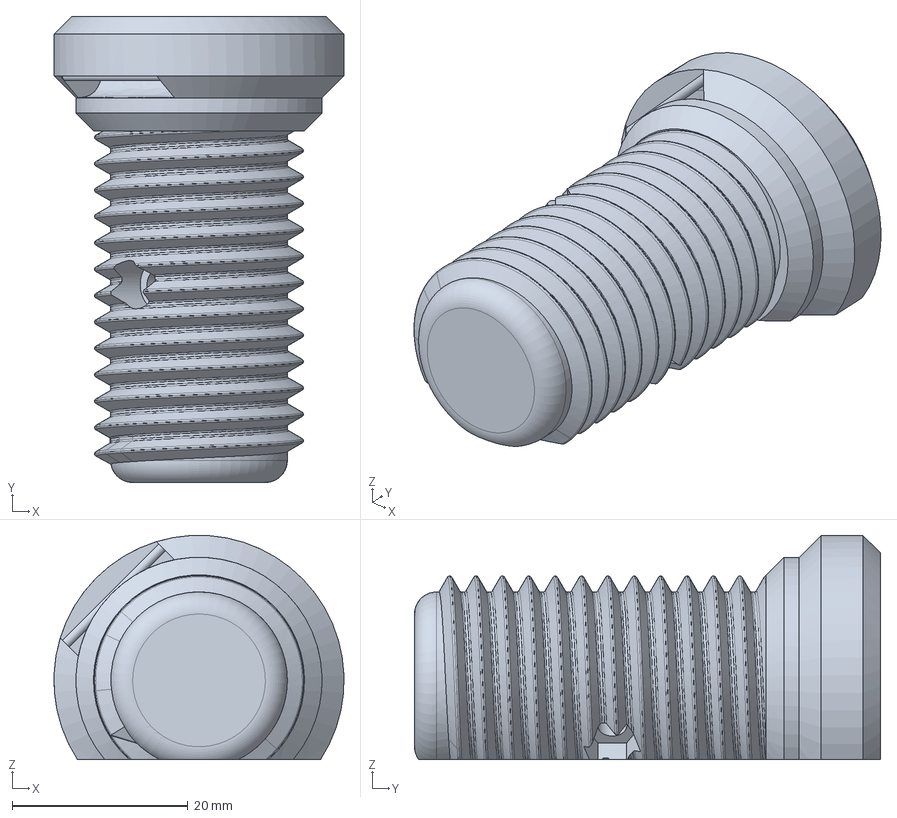
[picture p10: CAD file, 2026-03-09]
Hardware-Design/Heavy Version/MGN15H Belt Clamp and Toy Mount/STEP/Main Toy Thread.step
33.0 x 53.0 x 25.5 mm

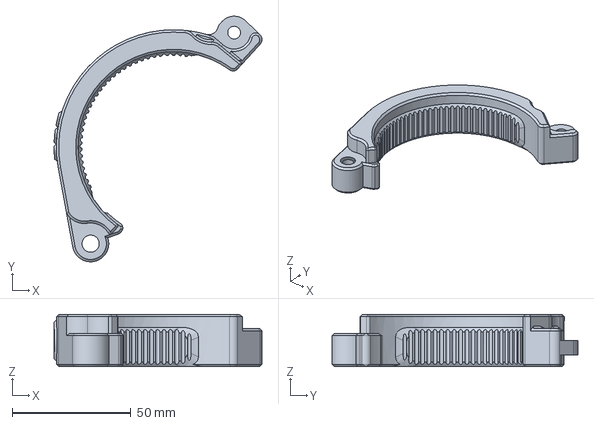
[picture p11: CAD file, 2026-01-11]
Hardware-Design/Alternative Pitclamp Mini Mount/STEP/Upper.step
87.4 x 103.3 x 22.0 mm

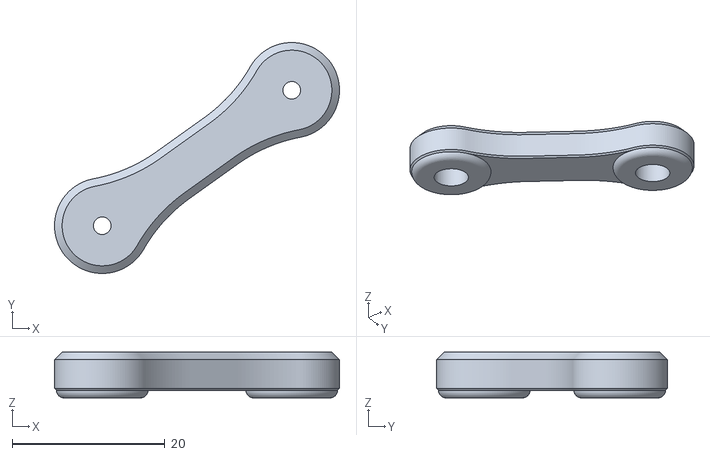
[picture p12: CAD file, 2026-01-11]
Hardware-Design/Alternative Pitclamp Mini Mount/STL/Dogbone (x2).stl
37.3 x 30.2 x 6.00

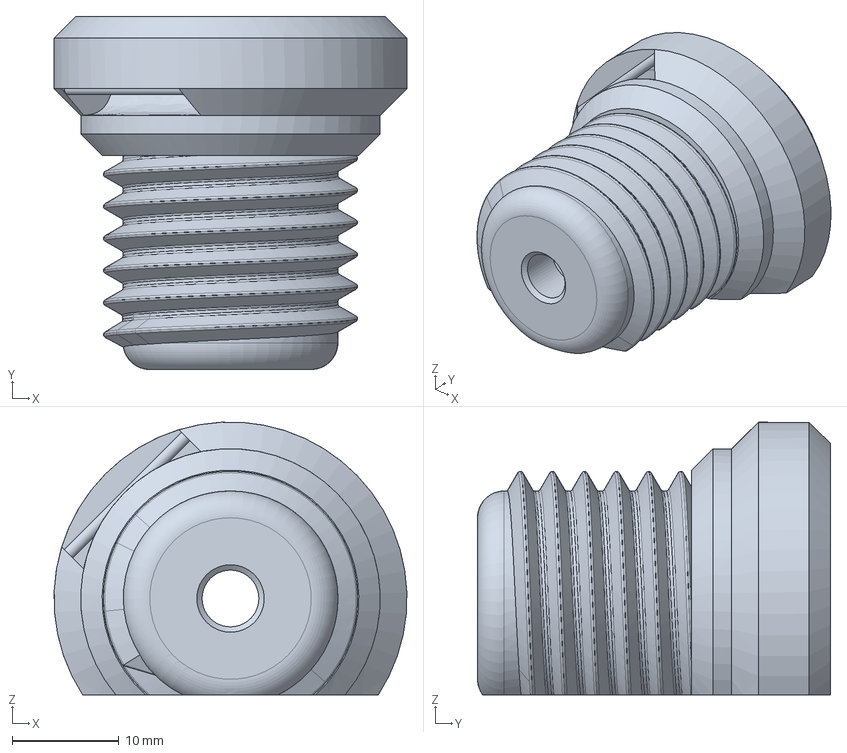
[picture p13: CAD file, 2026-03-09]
Hardware-Design/Heavy Version/MGN15H Belt Clamp and Toy Mount/STEP/Belt Tensioner.step
33.0 x 33.0 x 25.5 mm

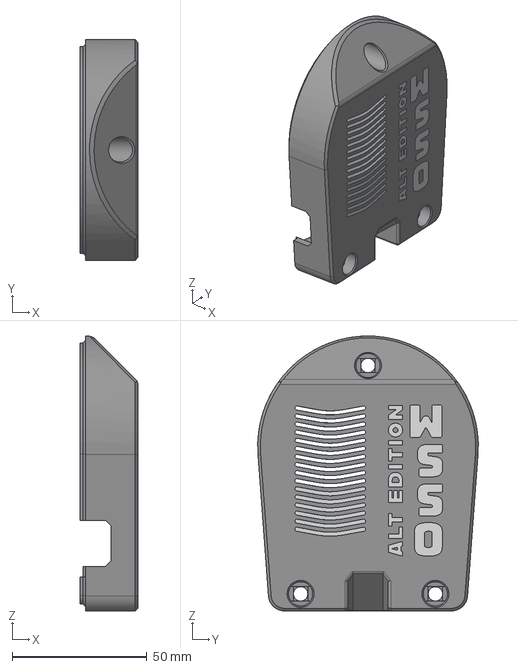
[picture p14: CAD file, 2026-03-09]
Hardware-Design/Heavy Version/MGN15H Main Mechanics/STEP/Belt Mechanics - Front.step
21.5 x 81.9 x 102.0 mm
BSHCS ANSI B18.3.1M - M3x0.5 x 12 Steel Grade 2 Plain x 2

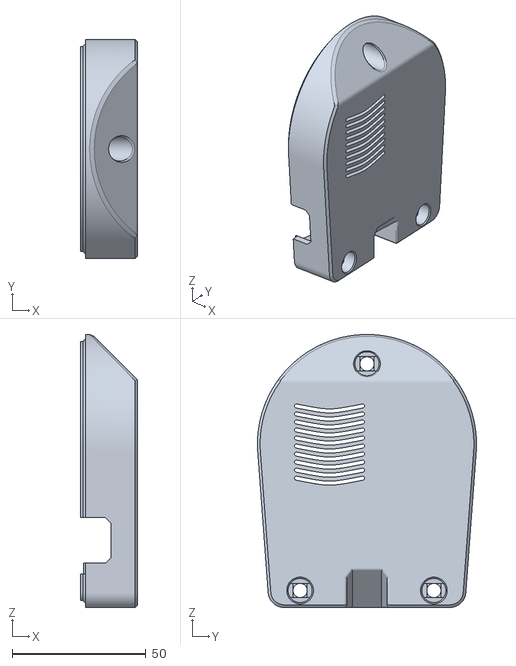
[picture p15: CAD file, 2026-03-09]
Hardware-Design/Heavy Version/MGN15H Main Mechanics/STL/Belt Mechanics - Front - Single Color - No Branding.stl
21.4 x 81.9 x 102.0

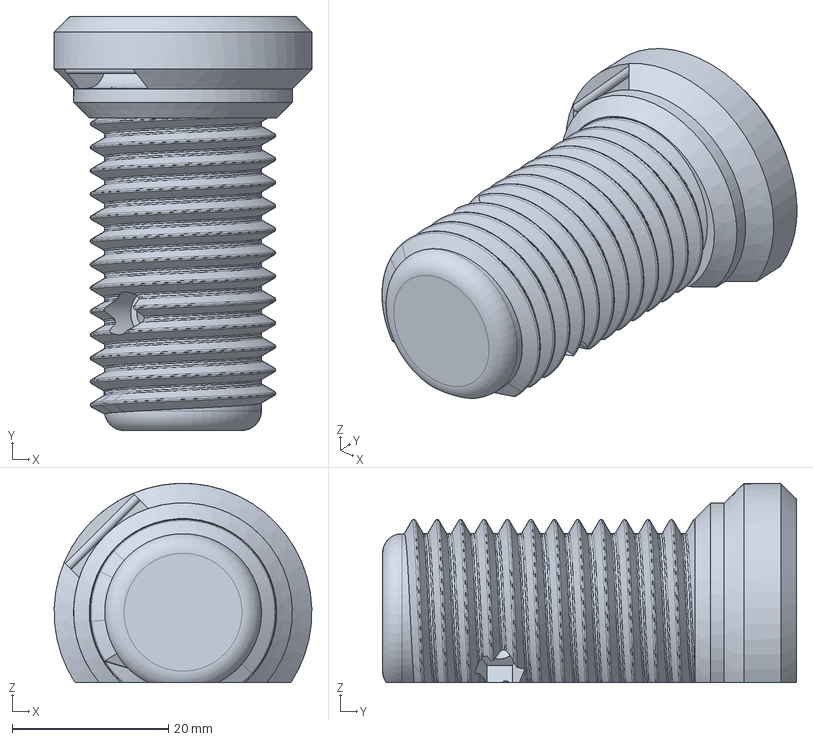
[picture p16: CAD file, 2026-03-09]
Hardware-Design/Light Version/MGN12H Belt Clamp and Toy Mount/STEP/Toy Mount Thread.step
33.0 x 53.0 x 25.5 mm

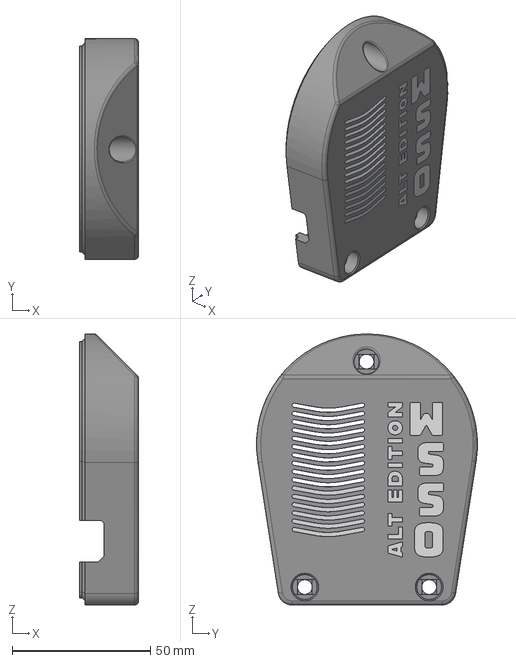
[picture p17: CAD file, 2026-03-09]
Hardware-Design/Light Version/MGN12H Main Mechanics/STEP/Belt Mechanics - Front.step
21.5 x 79.9 x 98.1 mm

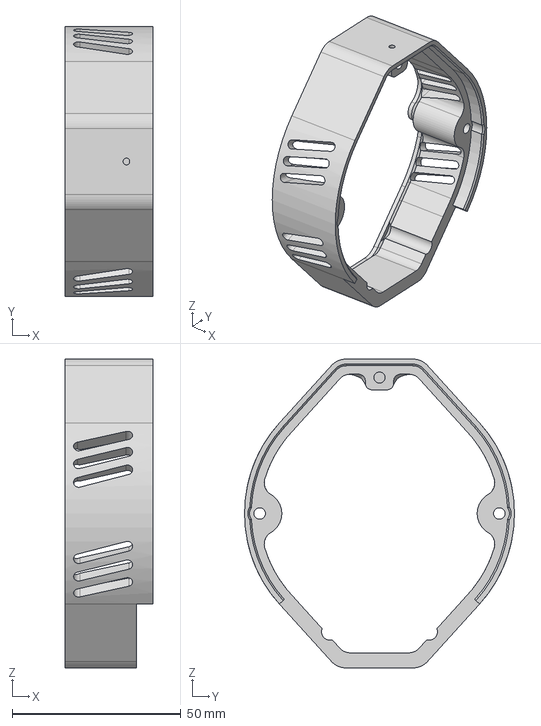
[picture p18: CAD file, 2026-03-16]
Hardware-Design/Motor and PCB Housing/STEP/Motor Mount - Spacer Ring.step
26.0 x 80.0 x 91.6 mm

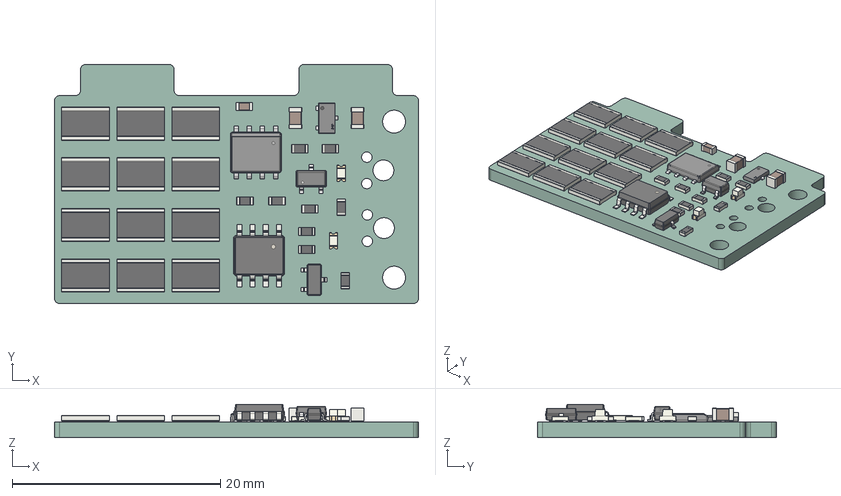
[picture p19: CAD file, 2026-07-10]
PCB-Design/Schematic and Design/Brakechopper/brakechopper_v1_1.step
35.0 x 23.0 x 3.20 mm
R_1218_3246Metric x 12
R_0603 x 9
C_0805 x 2
D_0603 x 2
SOT-23-3_L2.9-W1.6-P1.90-LS2.8-BR
SOT-23-3L_L2.9-W1.6-P1.90-LS2.8-BL
Q_SOT-23
PowerIntegrations_SO-8
SOP-8_L4.9-W3.9-P1.27-LS6.0-BL-1
C_0603
brakechopper_PCB

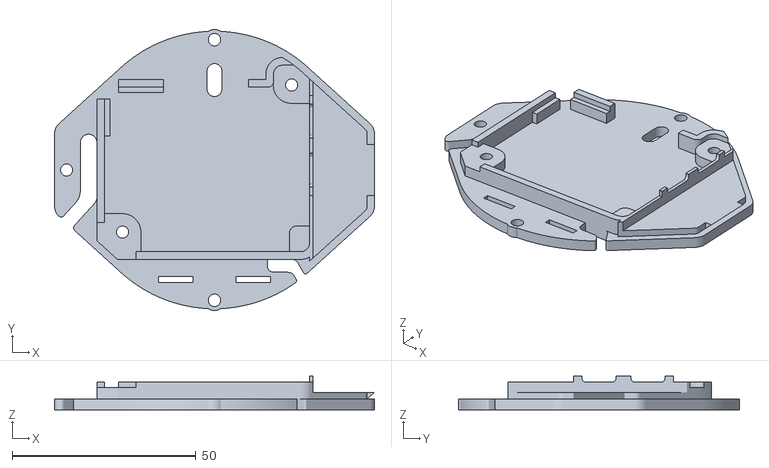
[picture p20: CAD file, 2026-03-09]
Print-Files/Heavy MGN15/Decorative Parts/Motor Mount - PCB Holder.stl
87.2 x 76.6 x 9.22

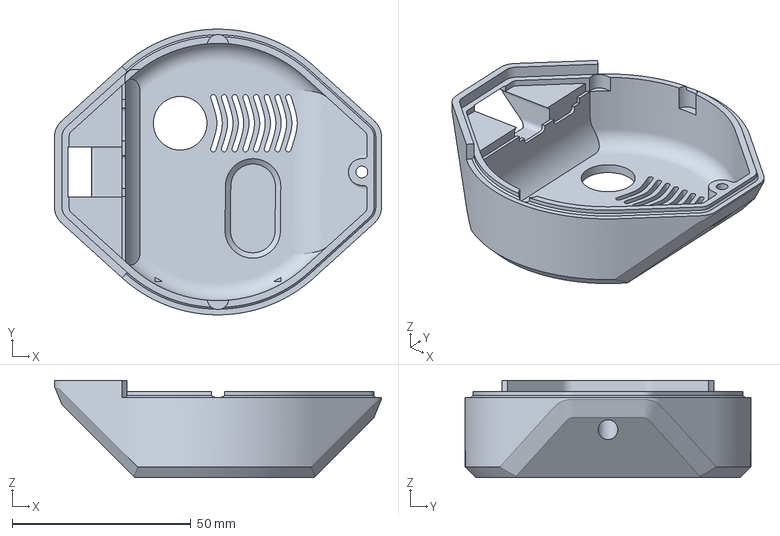
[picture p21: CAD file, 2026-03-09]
Print-Files/Light MGN12/Decorative Parts/Motor Mount - Top Cover - Multicolor.3mf
91.6 x 80.0 x 27.3 mm

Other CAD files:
Hardware-Design/Motor and PCB Housing/STEP/Motor Mount - Main Motor Clamp.step
Hardware-Design/Light Version/MGN12H Main Mechanics/STL/Belt Mechanics - Front - Multicolor.3mf
Hardware-Design/Alternative Pitclamp Mini Mount/STEP/Dogbone.step
Hardware-Design/Alternative Pitclamp Mini Mount/STEP/Handle.step
Hardware-Design/Alternative Pitclamp Mini Mount/STEP/Lower.step
Hardware-Design/Alternative Pitclamp Mini Mount/STL/Handle.stl
Hardware-Design/Alternative Pitclamp Mini Mount/STL/Lower.stl
Hardware-Design/Alternative Pitclamp Mini Mount/STL/Upper.stl
Hardware-Design/Heavy Version/MGN15H Belt Clamp and Toy Mount/STEP/Belt Tension Cover.step
Hardware-Design/Heavy Version/MGN15H Belt Clamp and Toy Mount/STEP/Clamp.step
Hardware-Design/Heavy Version/MGN15H Belt Clamp and Toy Mount/STEP/Nut.step
Hardware-Design/Heavy Version/MGN15H Main Mechanics/STEP/Belt Mechanics - Rear.step
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

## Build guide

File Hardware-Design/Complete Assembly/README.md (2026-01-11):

# Important Notice!

These assembly files are just here to give you an idea about how everything is assembled and fits together. Do not print the parts from these files since they are not guaranteed to be up to date! (I might sometimes make a small change in a part and not constantly update these files)

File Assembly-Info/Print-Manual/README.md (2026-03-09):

# OSSM ALT Edition — 3D Print Manual

## Introduction

This manual covers all 3D printed parts for the OSSM ALT Edition (excluding Pitclamp) and provides guidance on print settings, part orientation, and support material usage to ensure successful prints.

The OSSM ALT Edition comes in two variants:

- **Heavy (MGN15H)** — uses MGN15H linear rails
- **Light (MGN12H)** — uses MGN12H linear rails

Print settings described in this manual are intercompatible between both variants unless explicitly noted otherwise.

---

## Tested Printers & Materials

The table below lists printers and materials that have been tested. Use this as a reference when choosing your setup or when getting things printed by an external party.

| Printer | Tested Materials | Recommended Printer | Notes | User
|---|---|---|---|---|
| Prusa XL | PLA / PET-G | Yes | No troubles. Tolerances are fine with default Prusa Profiles. PET-G tolerances are a bit tighter which makes it more difficult to place embedded nuts. | BuildingRandomThings
| Prusa Core One (L) | PLA | Yes | No troubles. Tolerances are fine with default Prusa Profiles. | BuildingRandomThings
| Bambulab A1 | PLA Basic, Tough PLA | Yes | No troubles. Tolerances are fine with default profiles. Tough PLA embedded nuts are tighter though. | BuildingRandomThings
| Bambulab X1C Carbon | Matte PLA | Yes | No troubles. Tolerances are fine, but the matte prints are a lot weaker (especially when printed at high speeds) | BuildingRandomThings
| Ultimaker S5 | PLA | No | This is an older printer that works fine for a lot of things, but the tolerances are not up to par with newer printers (partially due to the 2.85mm filament). Therefore it is not recommended. This printer was tested since it is very common at makerspaces | BuildingRandomThings

---

## General Print Settings

These settings apply to all parts unless a specific part section states otherwise. 

| Setting | Recommended Value |
|---|---|
| Layer height | 0.2mm (Important due to bridging designs)|
| Wall count / Perimeters | 6 for mechanical parts, 2 for decorative |
| Top/Bottom layers | 5 top and 3 bottom @0.2mm layer height |
| Infill percentage | 25% strength & 15% decorative|
| Infill pattern | Grid |
| Print speed | High speeds are detrimental for strength. Outer walls are printed at reduced speed for better quality (60mm/s). I don't recommend going over 200mm/s for inner walls and infill (mechanical parts). Speed is much less of a concern for decorative pars.  
| Support | This design is optimized for minimal support. There is only 1 part that needs support. Please do not place support unless specifically mentioned. |
| Recommended Material | PLA with good settings is more than strong enough. Tough PLA is recommended for parts requiring additional durability or impact resistance, but not necessary for 'general usage'. I don't recommend matte/satin filaments due to their reduced strength/brittleness. PET-G also works fine and can handle impacts better, but is less rigid. |
| Total Filament | ±315g |

---

## Parts

---

### 1. Belt Clamp & Toy Mount (combined)

**Description:**
> _Belt tensioners / clamp & M24 accessory mount. These parts are redesigned and tested for extreme abuse. However, printing orientation is very important for strength so please pay attention to the image below and use the recommended settings. Also avoid matte/silk or other weak materials._

**Print Settings:**

| Setting | Value |
|---|---|
| Print Profile | Strength |
| Layer height | 0.2mm |
| Infill | 25% |
| Walls / Perimeters | 6 |
| Weight Estimate | 65g |
| Print Time | ±3h |

**Orientation:**

> _Reference the image below._

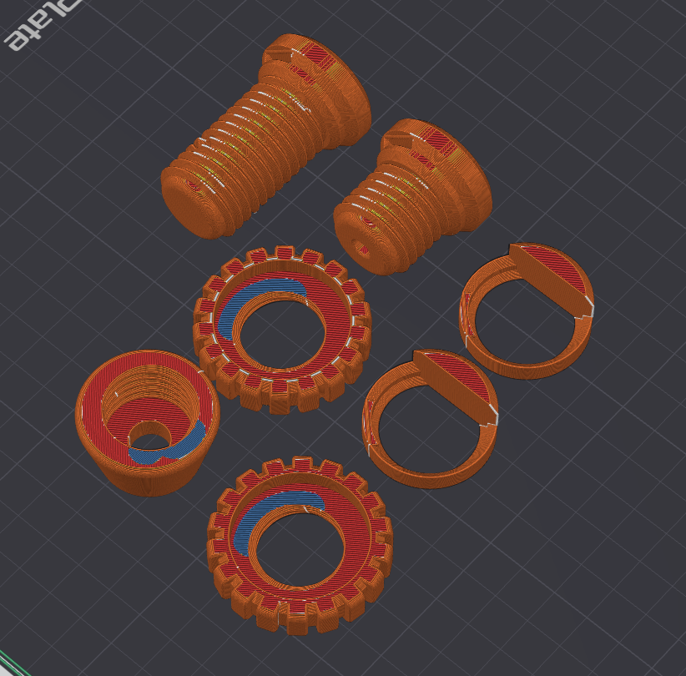
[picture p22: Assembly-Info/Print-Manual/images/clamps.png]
Belt Clamp & Toy Mount orientation


**Support Material:**

- Required: No
- Support type: _none_
- Notes: _Please don't use supports._

**Notes:**
> _This should fit all the original OSSM M24 Hardware. The length of the thread is a little bit shorter than standard, because I deem that unnecessary and did not like the look of it. Theoretically the original clamps should work as well for the MGN12 version, but this is untested. I've already designed several accessories that fit well with these parts such as a suction cup mount (check accessory folder)._

---

### 2A. Belt Mechanics Bottom

**Description:**
> _This is mechanically the most important part. Print with strength profiles (i.e. 6 perimeters, 25% infill) and avoid matte/silk/other weak materials. There should not be any play on the dowels and normally you would have to press/hammer it in firm._

**Print Settings:**

| Setting | Value |
|---|---|
| Print Profile | Strength |
| Layer height | 0.2mm |
| Infill | 25% |
| Walls / Perimeters | 6 |
| Weight Estimate | 50g |
| Print Time | ±2h |

**Orientation:**

> _Reference the image below. No support is needed since all the holes have a sequential bridging design. Printing support only leads to worse print quality in this case._

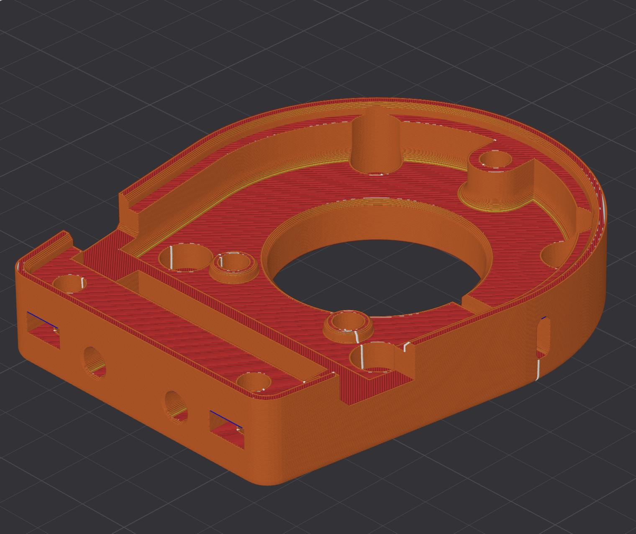
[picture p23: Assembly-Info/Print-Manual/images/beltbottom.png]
Belt Mechanics orientation


**Support Material:**

- Required: No
- Support type: _None_

**Notes:**
> _The hole on the side allows you to tighten the grub screw even after it is assembled for easy maintenance / extra tightening of this part. The reason for this is that i have noticed that people don't tend to tighten the grub screw enough which may lead to belt slipping._

---

### 2B. Belt Mechanics Top

**Description:**
> _This is mechanically the most important part. Print with strength profiles (i.e. 6 perimeters, 25% infill) and avoid matte/silk/other weak materials. There should not be any play on the dowels and normally you would have to press/hammer it in firm._

**Print Settings:**

| Setting | Value |
|---|---|
| Print Profile | Strength |
| Layer height | 0.2mm |
| Infill | 25% |
| Walls / Perimeters | 6 |
| Weight Estimate | 60g |
| Print Time | ±2.5h |

**Orientation:**

> _Reference the image below. No support is needed since all the holes have a sequential bridging design. Printing support only leads to worse print quality in this case._

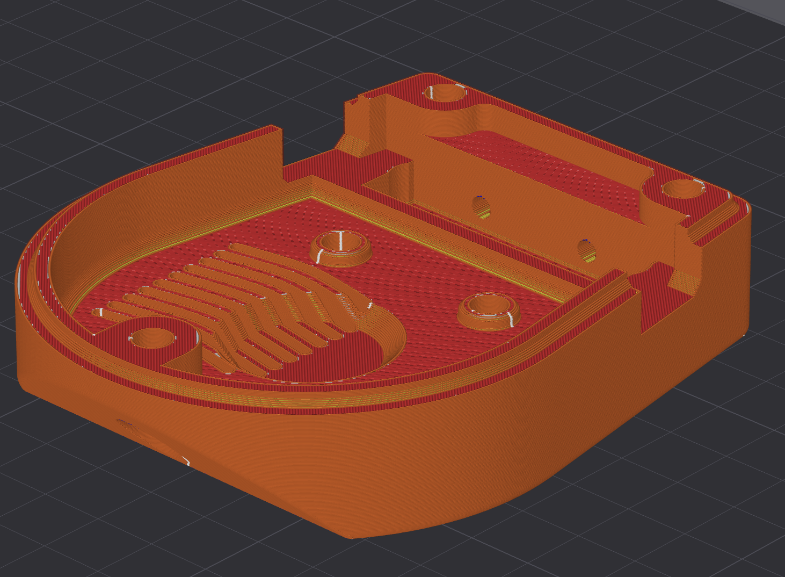
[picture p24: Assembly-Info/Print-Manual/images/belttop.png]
Belt Mechanics orientation


**Support Material:**

- Required: No
- Support type: _None_

**Notes:**
> _The hole on the side allows you to tighten the grub screw even after it is assembled for easy maintenance / extra tightening of this part. The reason for this is that i have noticed that people don't tend to tighten the grub screw enough which may lead to belt slipping._

---

### 3. Motor Mount

**Description:**
> _This part secures the motor in place. Strenght is crucial, so print at slow speeds with a strong material and a minimum of 4 perimeters. Some force might be required to get the M5 lock nuts in place. Normal M5 nuts will fit with more ease, but might loosen over time due to vibrations._

**Recommended Print Settings:**

| Setting | Value |
|---|---|
|Print Profiles | Strenght |
| Layer height | 0.2mm|
| Infill | 25% |
| Walls / Perimeters | 6 |
| Weight Estimate | ±80g |
| Brim | Generally not needed, but can prevent warping in case of problems with bed adhesion. Use it if you are uncertain / or generally have problems with adhesion. 
| Time Estimate | ±3h |

**Orientation:**

> _Print as shown in the image below. Supports should only be placed the bottom M5 mounts. The other parts can and should be bridged._

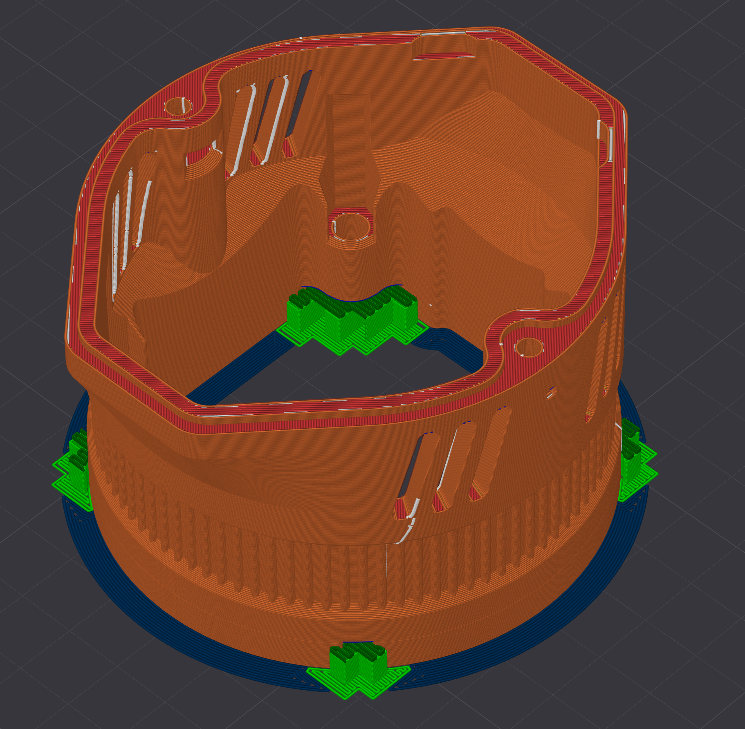
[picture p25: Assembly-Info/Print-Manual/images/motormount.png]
Motor Mount orientation

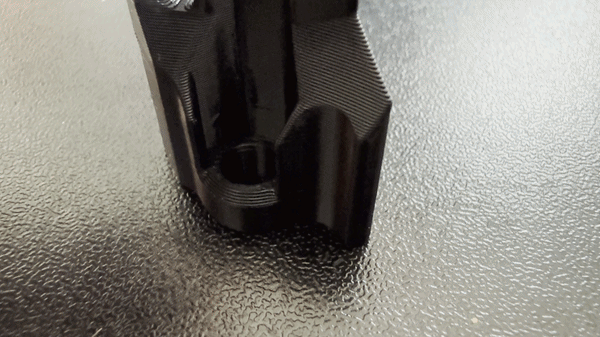
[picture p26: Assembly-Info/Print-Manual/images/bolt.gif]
Nut


**Support Material:**

- Required: Yes
- Support type: _Normal (Tree support is easier to remove, but normal support has a better surface finish on flat areas)._
- Support placement: _Build plate only_
- Notes: _Avoid placing support in m3 slots (use support blockers). All nut slots are designed with sequential bridging and therefore don't need any support._

**Notes:**
> _Please watch the orientation of this part during assembly. The side that says "RS485" should be placed in line with the white RS485 connector on the gold motor and oriented towards the top side of the machine._
> 
> _The M3 nuts might require a little force to press into their slots securely. I've deliberately chosen not to make the holes any wider, because it made assembly horrible (you don't want nuts to fall out during assembly). I find it easiest to press them in halfway by hand and then push the last bit with a screwdriver._

---

### 4. Motor Spacer

**Description:**
> _This part is placed on top of the motor mount. It has no structural requirements and serves as a spacer only. Print with 'decorative' settings. This part does not need any support material, but an inner brim is recommended for better adhesion since warping will make alignment visually less attractive and may affect the overall fit._

**Recommended Print Settings:**

| Setting | Value |
|---|---|
|Print Profiles | Decorative |
| Layer height | 0.2mm|
| Infill | 15% |
| Walls / Perimeters | 2 |
| Weight Estimate | ±20g |
| Time Estimate | ±1h |

**Orientation:**

> _Print as shown in the image below._

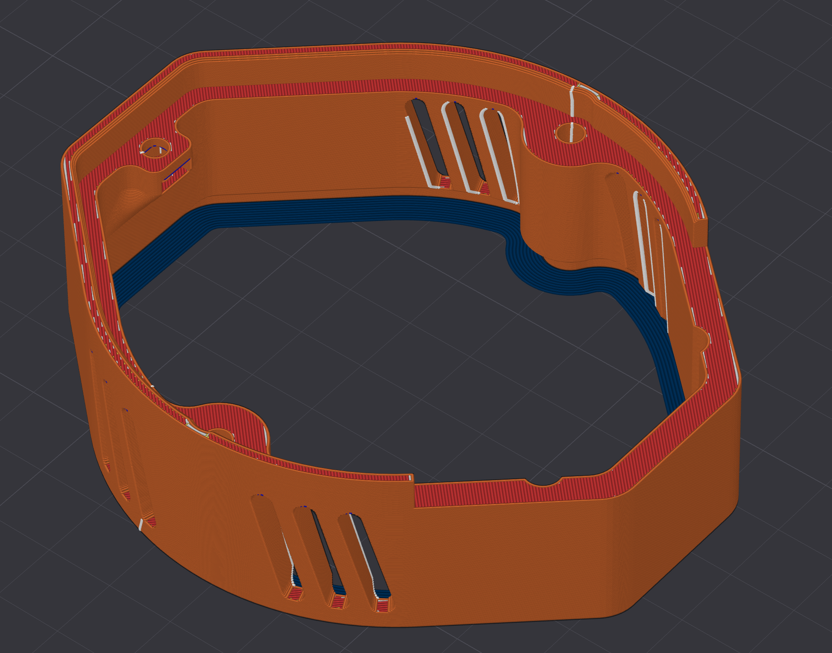
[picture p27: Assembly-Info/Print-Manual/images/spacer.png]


**Support Material:**

- Required: No
- Notes: _Avoid placing supports. This will only make insertion of the nuts more difficult._

**Notes:**
> _Tolerances can be a little bit different for different nuts and printers. The M3 nuts might require a little force to press into their slots securely. I've deliberately chosen not to make the holes any wider, because it made assembly horrible (you don't want nuts to fall out during assembly). I find it easiest to press them in halfway by hand and then push the last bit with a screwdriver._

---

### 5. PCB Mount

**Description:**
> _This part secures the main pcb and optional brake pcb while increasing rigidity of the overall design. Again: do not place supports. The nut slots are designed with sequential bridging in mind._

**Recommended Print Settings:**

| Setting | Value |
|---|---|
|Print Profiles | Decorative |
| Layer height | 0.2mm|
| Infill | 15% |
| Walls / Perimeters | 2 |
| Weight Estimate | ±15g |
| Time Estimate | ±30min |

**Orientation:**

> _Print as shown in the image below. No supports._

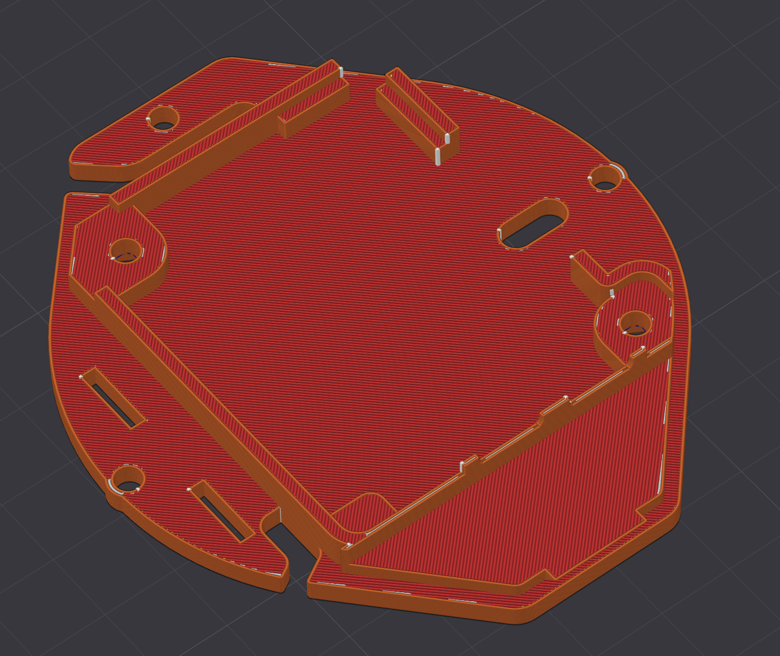
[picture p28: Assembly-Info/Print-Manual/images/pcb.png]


**Support Material:**

- Required: No

**Notes:**
> _The M3 nuts in this part have a tighter fit which requires pressing them in. It may help to temporarily screw a bolt in the nut and press it in that way. It is necessary for these nuts to be tight since they will otherwise fall out during assembly. If they somehow are loose, glue them in place._

---

### 6. Motor Top Cover

**Description:**
> _This part is primarily decorative and is meant to cover the pcb's. There are several versions in the repository. With logo's (print with an AMS/Toolchanger), without logos' and with/without the RGB led cover._

**Recommended Print Settings:**

| Setting | Value |
|---|---|
| Print Profiles | Decorative |
| Layer height | 0.2mm |
| Infill | 15% |
| Walls / Perimeters | 2 |
| Weight Estimate | ±25g |
| Time Estimate | ±1.5h |

**Orientation:**

> _Reference the image below for orientation._

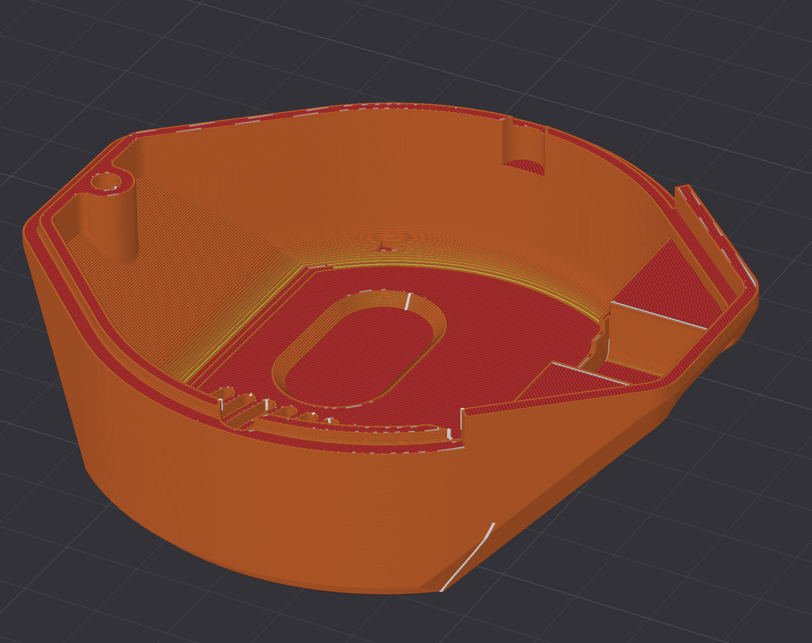
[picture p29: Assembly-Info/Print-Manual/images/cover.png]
Motor Cover & PCB Holder orientation


**Support Material:**

- Required: No
- Support type: _None_
**Notes:**
> _You can print this part at lower layer heights for increased detail/smoothness, but this may affect the sequential bridging that was designed in place._

---

### 7. Optional Led Cover

**Description:**
> _Optional transparent cover the RGB led. Print with a translucent material such as PET-G._

**Recommended Print Settings:**

| Setting | Value |
|---|---|
| Print Profiles | Decorative |
| Layer height | 0.2mm |
| Infill | 5% |
| Infill Type | Grid |
| Walls / Perimeters | 2 |
| Top Layers | 5 |
| Bottom Layers | 3 |
| Surface Pattern | Concentric |
| Weight Estimate | ±1g |
| Time Estimate | ±10min |

**Orientation:**

> _Reference the image below. Non-textured build plates give the best results._

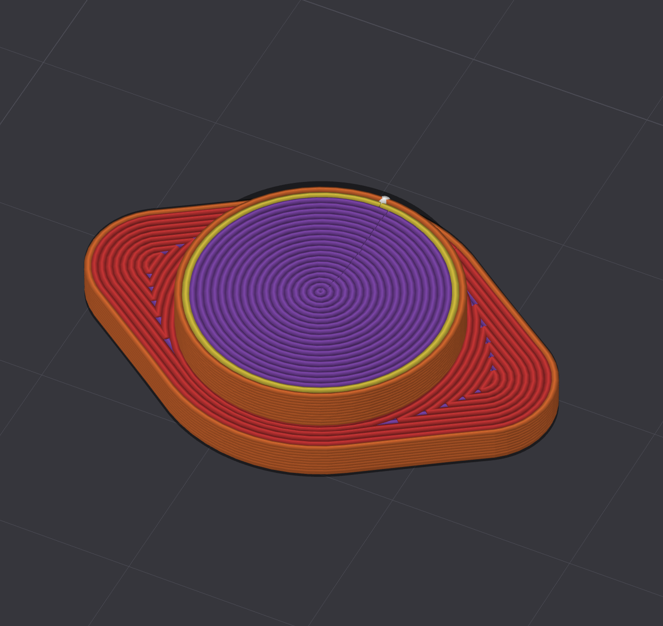
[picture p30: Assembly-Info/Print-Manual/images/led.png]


**Notes:**
> _Preferably use a smooth build plate. There are several guides online for increased transparency, but the LED is really bright so that should not be necessary._
> 
> _this part is a press fit. If it does not stay in place, secure it with some glue_

---

## Troubleshooting

| Problem | Possible Cause | Solution |
|---|---|---|
| Part doesn't fit / too tight | Over-extrusion or elephant foot | Calibrate extrusion multiplier, enable first layer compensation. Motor nuts are supposed to be tight and might require some force.  |
| Warping | Poor bed adhesion or cooling | Use brim, printing adhesive, increase bed temperature, reduce fan speed for first layers |
| Layer delamination | Too low temperature or too fast | Increase nozzle temp, reduce speed, reduce cooling |

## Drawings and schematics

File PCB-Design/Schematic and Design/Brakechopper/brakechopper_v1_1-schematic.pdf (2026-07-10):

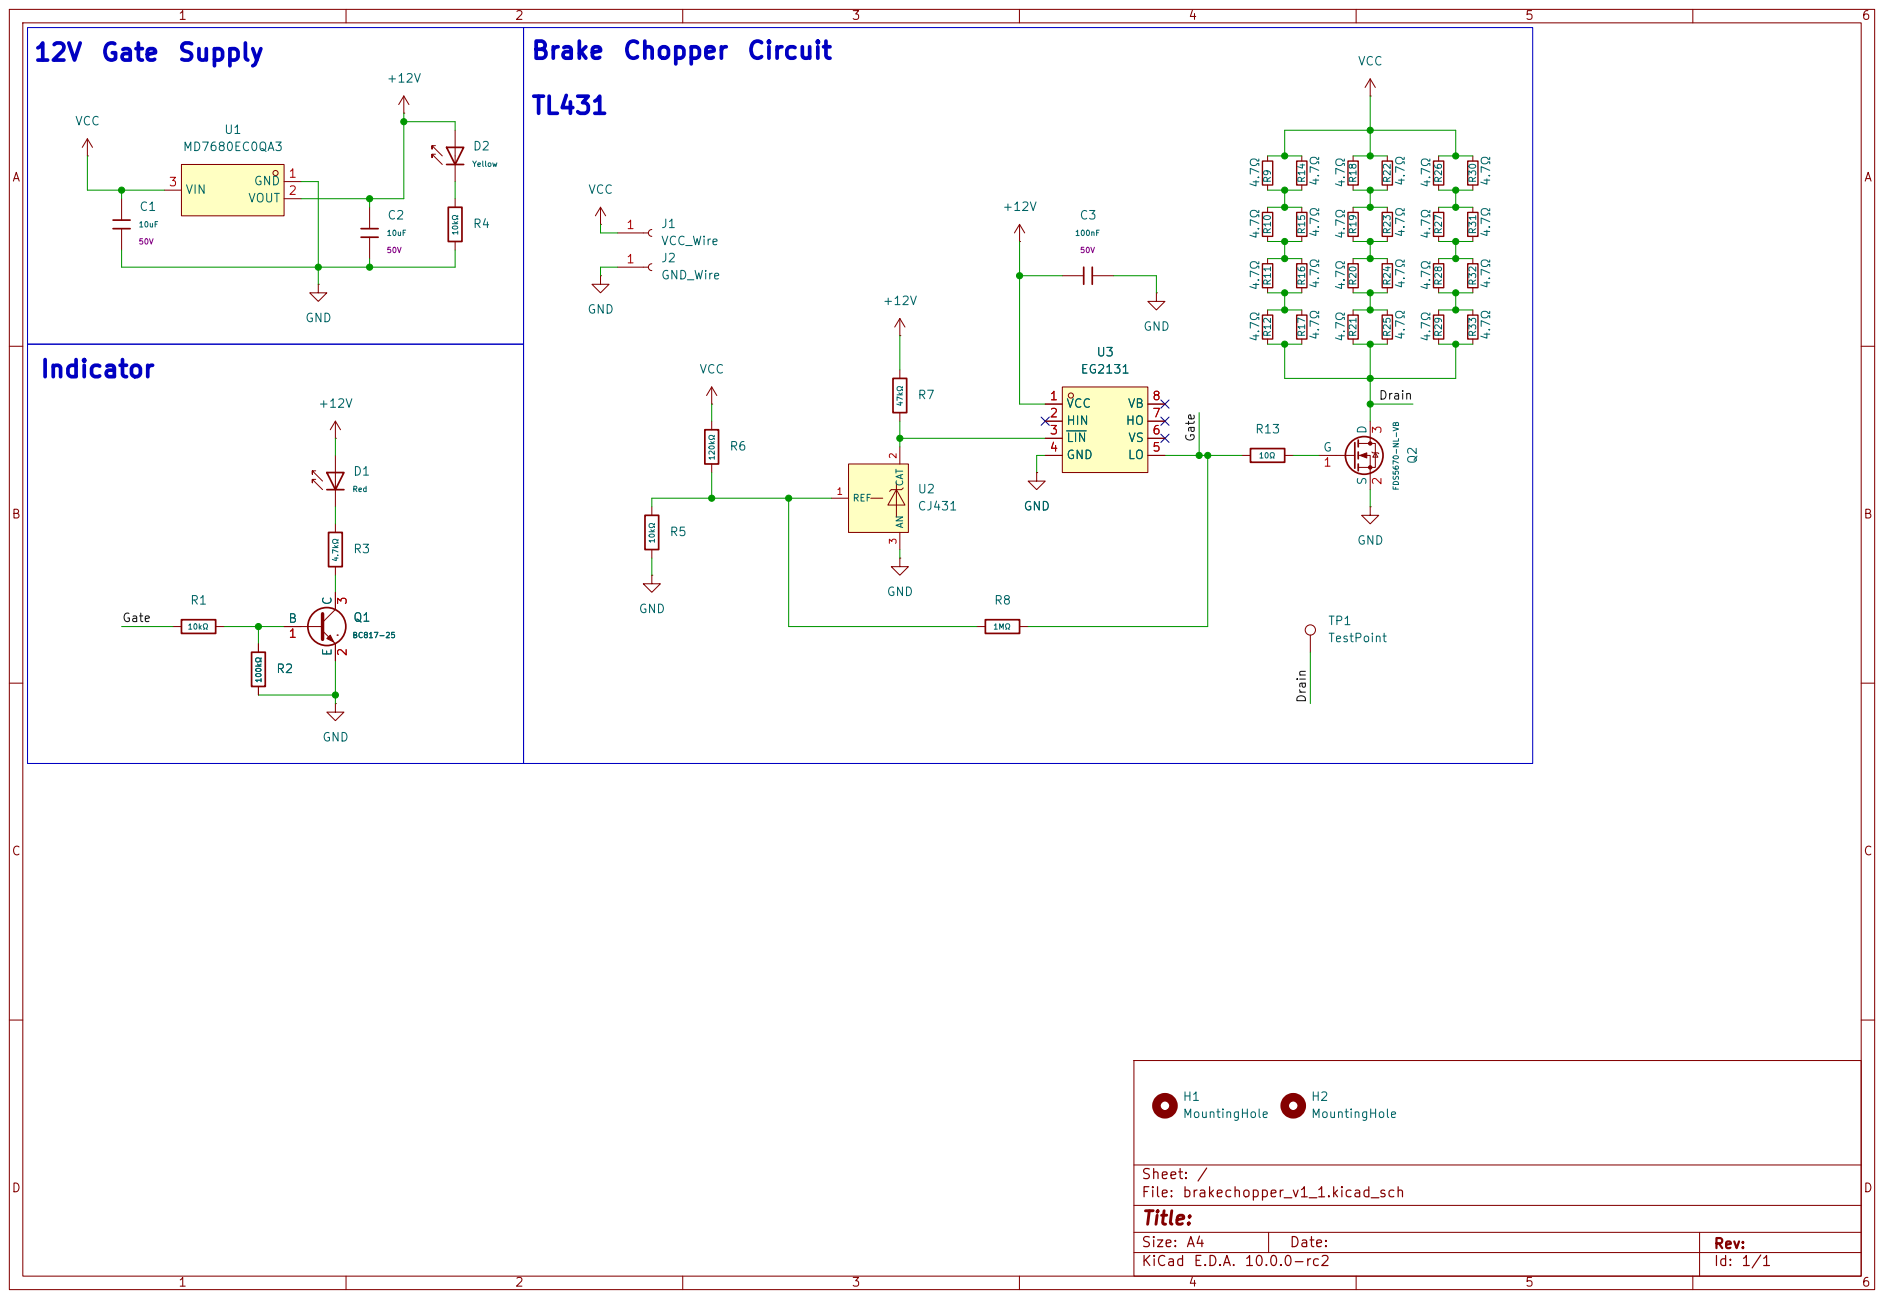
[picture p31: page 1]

Size: A4 | Rev:
KiCad E.D.A. 10.0.0-rc2 | Id: 1/1

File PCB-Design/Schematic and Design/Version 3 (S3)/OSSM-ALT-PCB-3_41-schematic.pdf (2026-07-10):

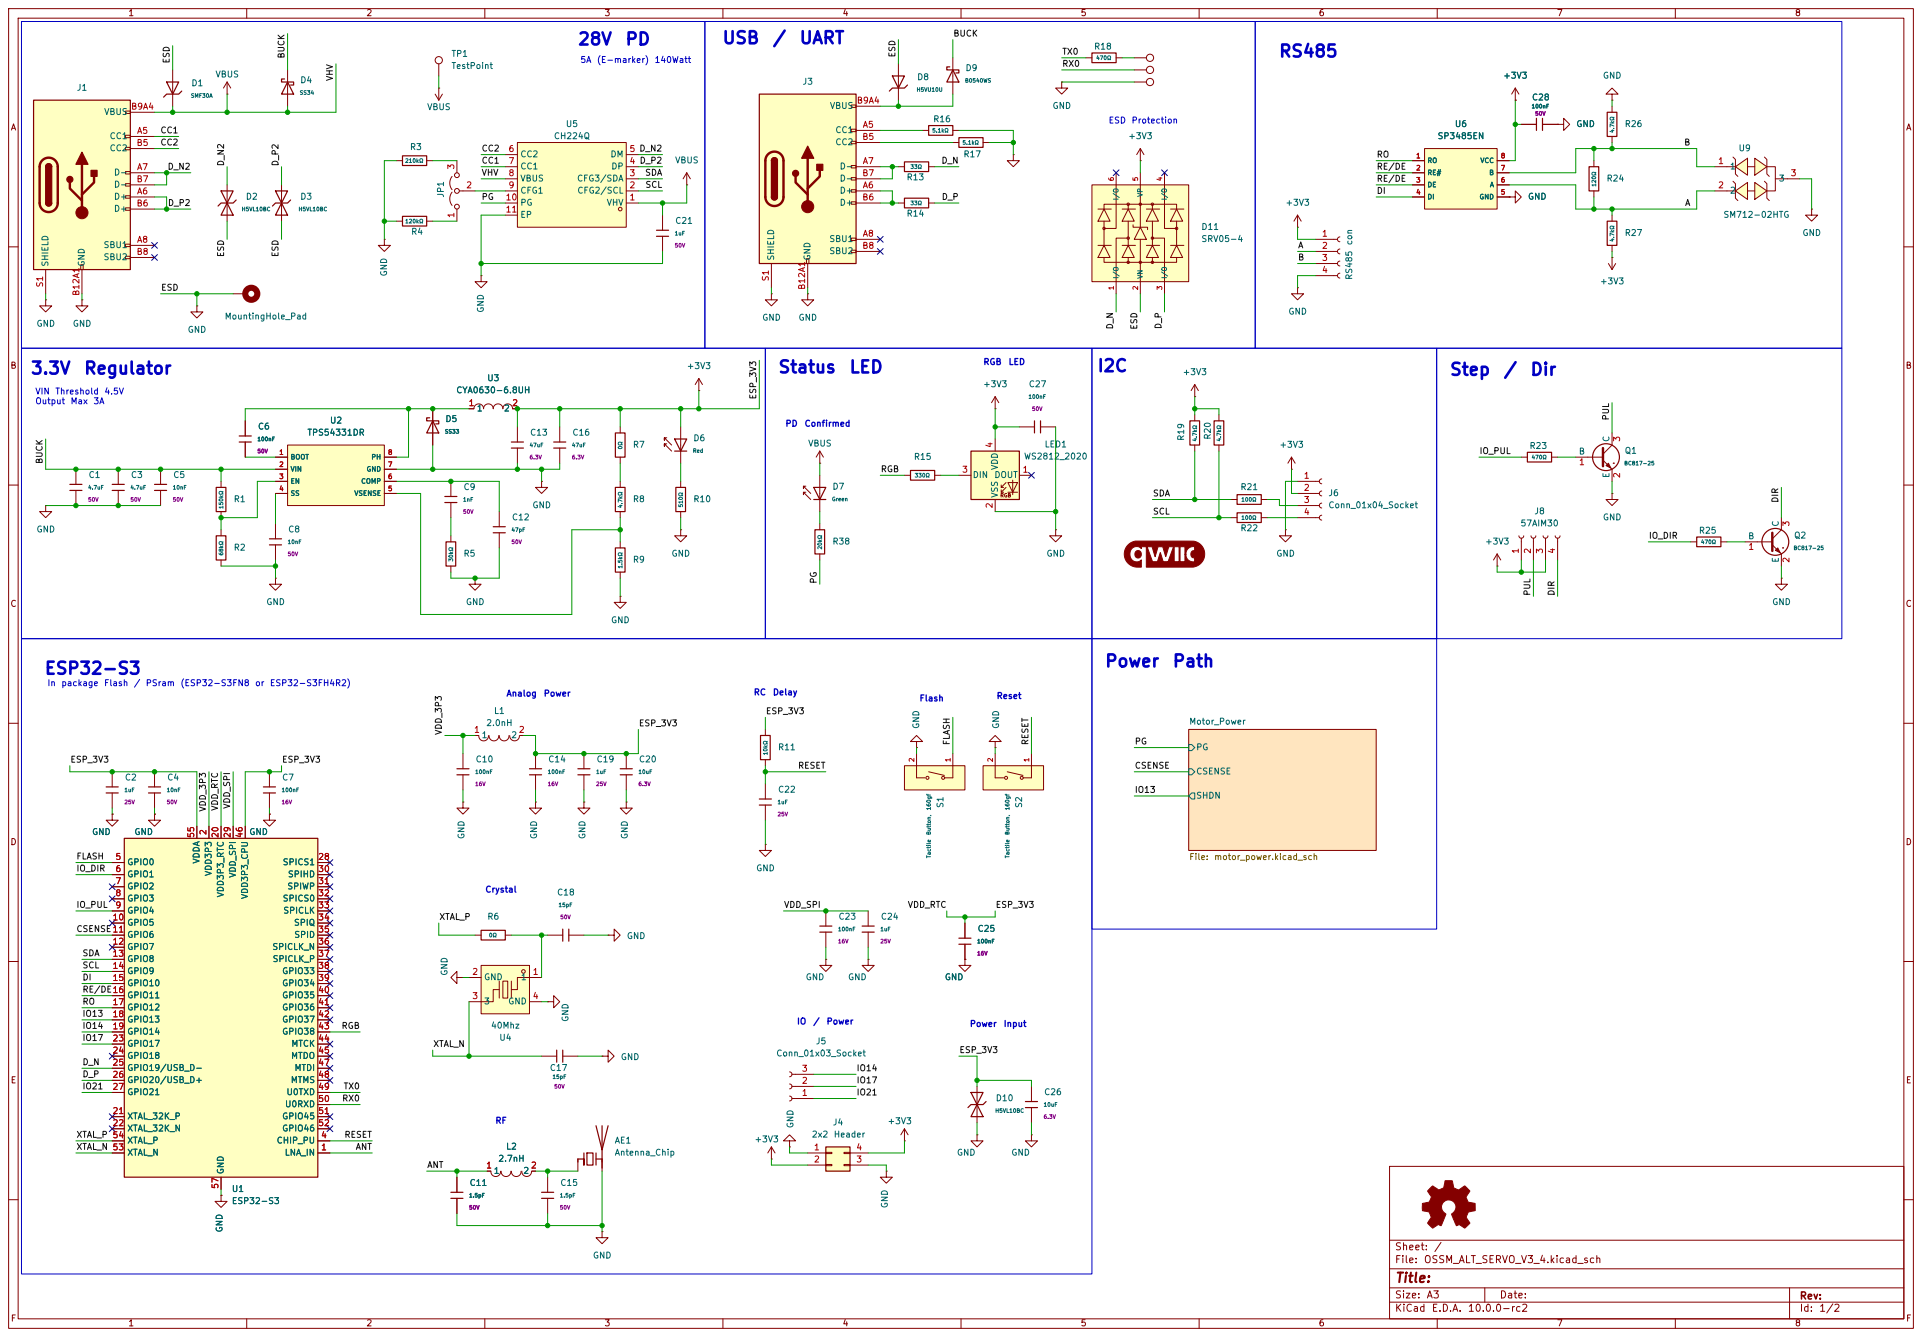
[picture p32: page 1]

Status LED | | IO13 ESD

GND

In package Flash / PSram (ESP32-S3FN8 or ESP32-S3FH4R2) RC Delay L1

Size: A3 | Rev: | F Date:
KiCad E.D.A. 10.0.0-rc2 | Id: 1/2

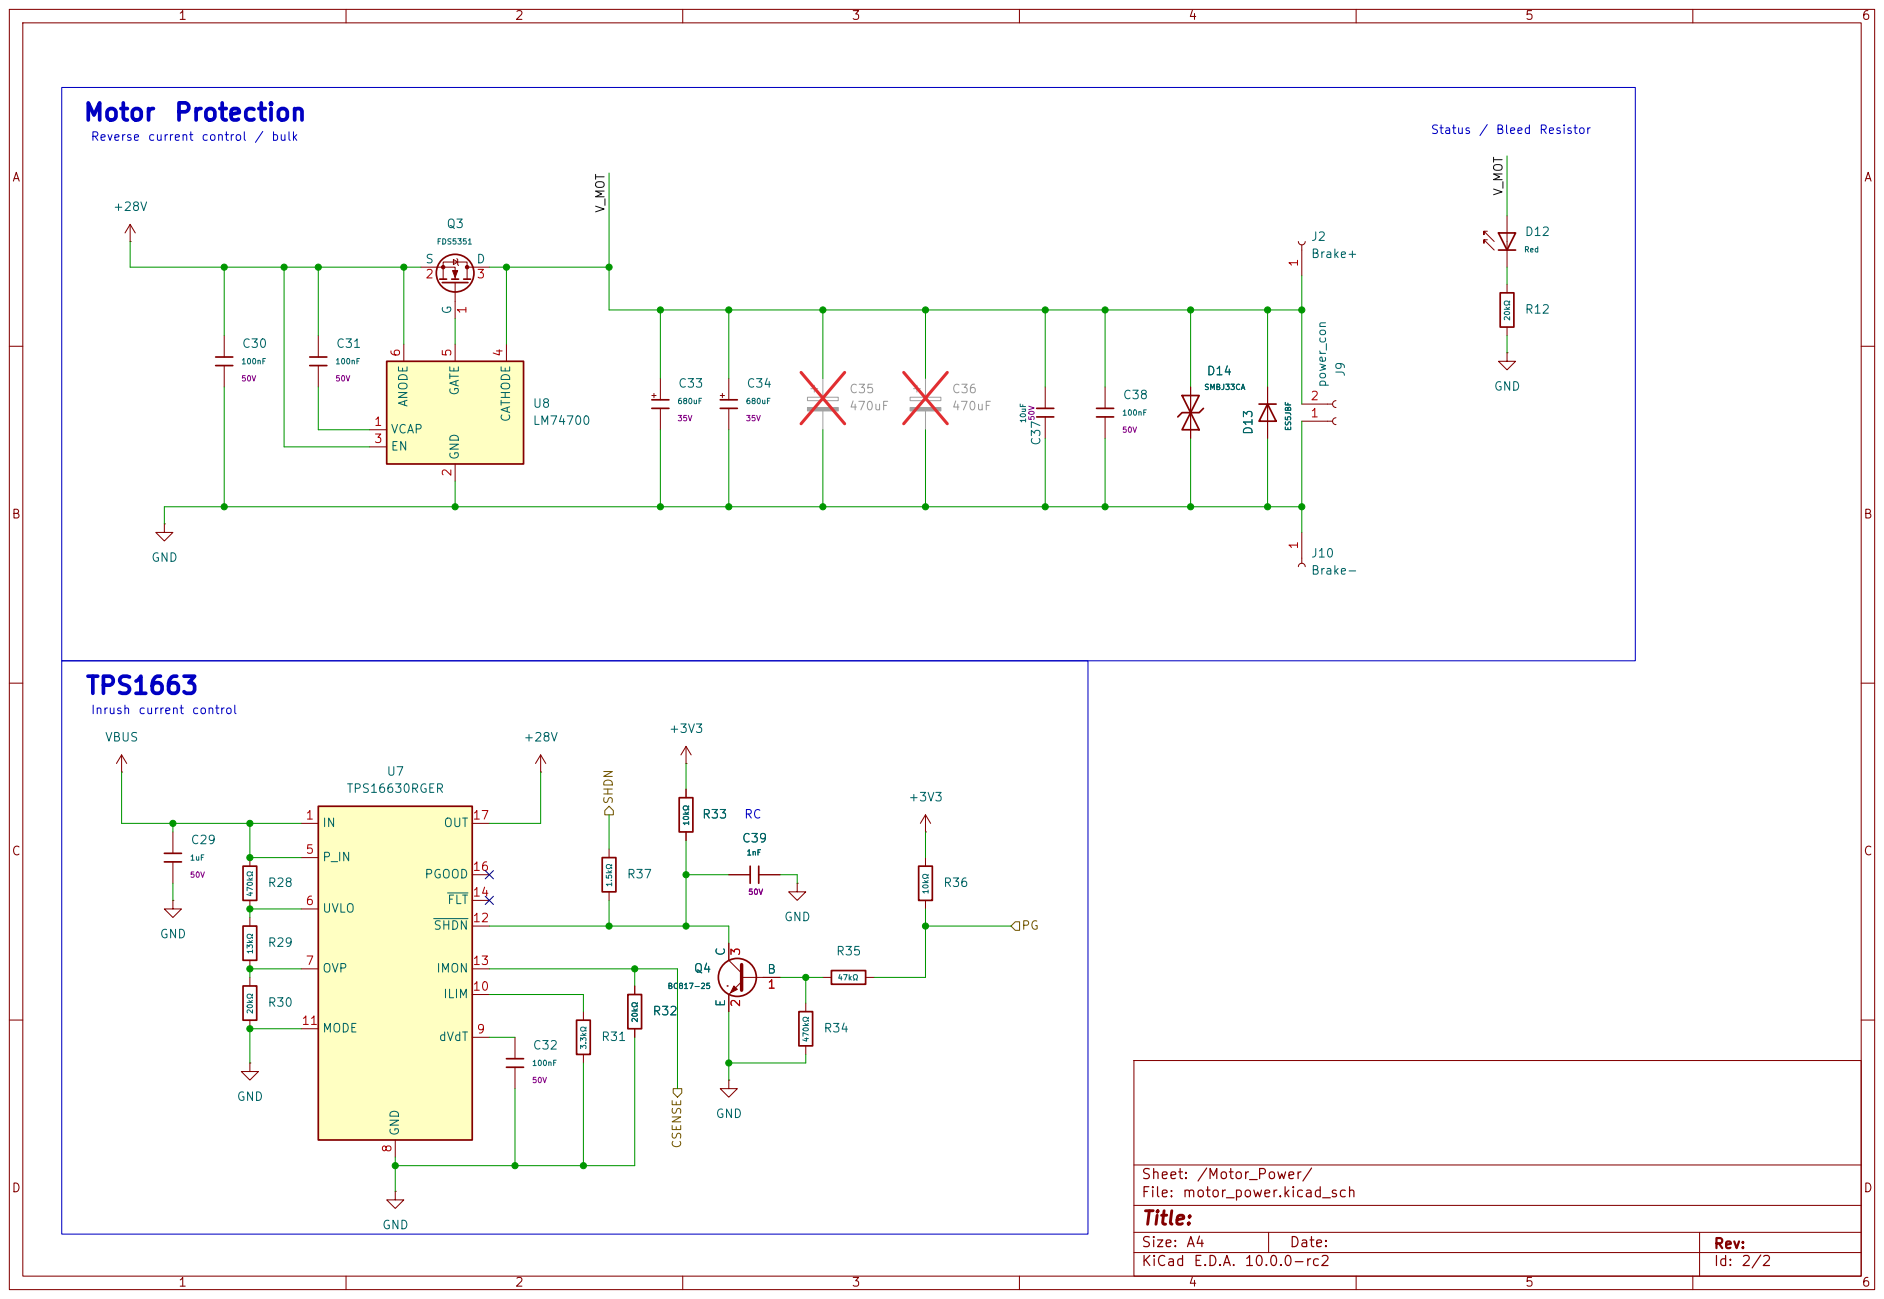
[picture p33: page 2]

Reverse current control / bulk Motor Protection

Status / Bleed Resistor RC

Size: A4 | Rev:
KiCad E.D.A. 10.0.0-rc2 | Id: 2/2

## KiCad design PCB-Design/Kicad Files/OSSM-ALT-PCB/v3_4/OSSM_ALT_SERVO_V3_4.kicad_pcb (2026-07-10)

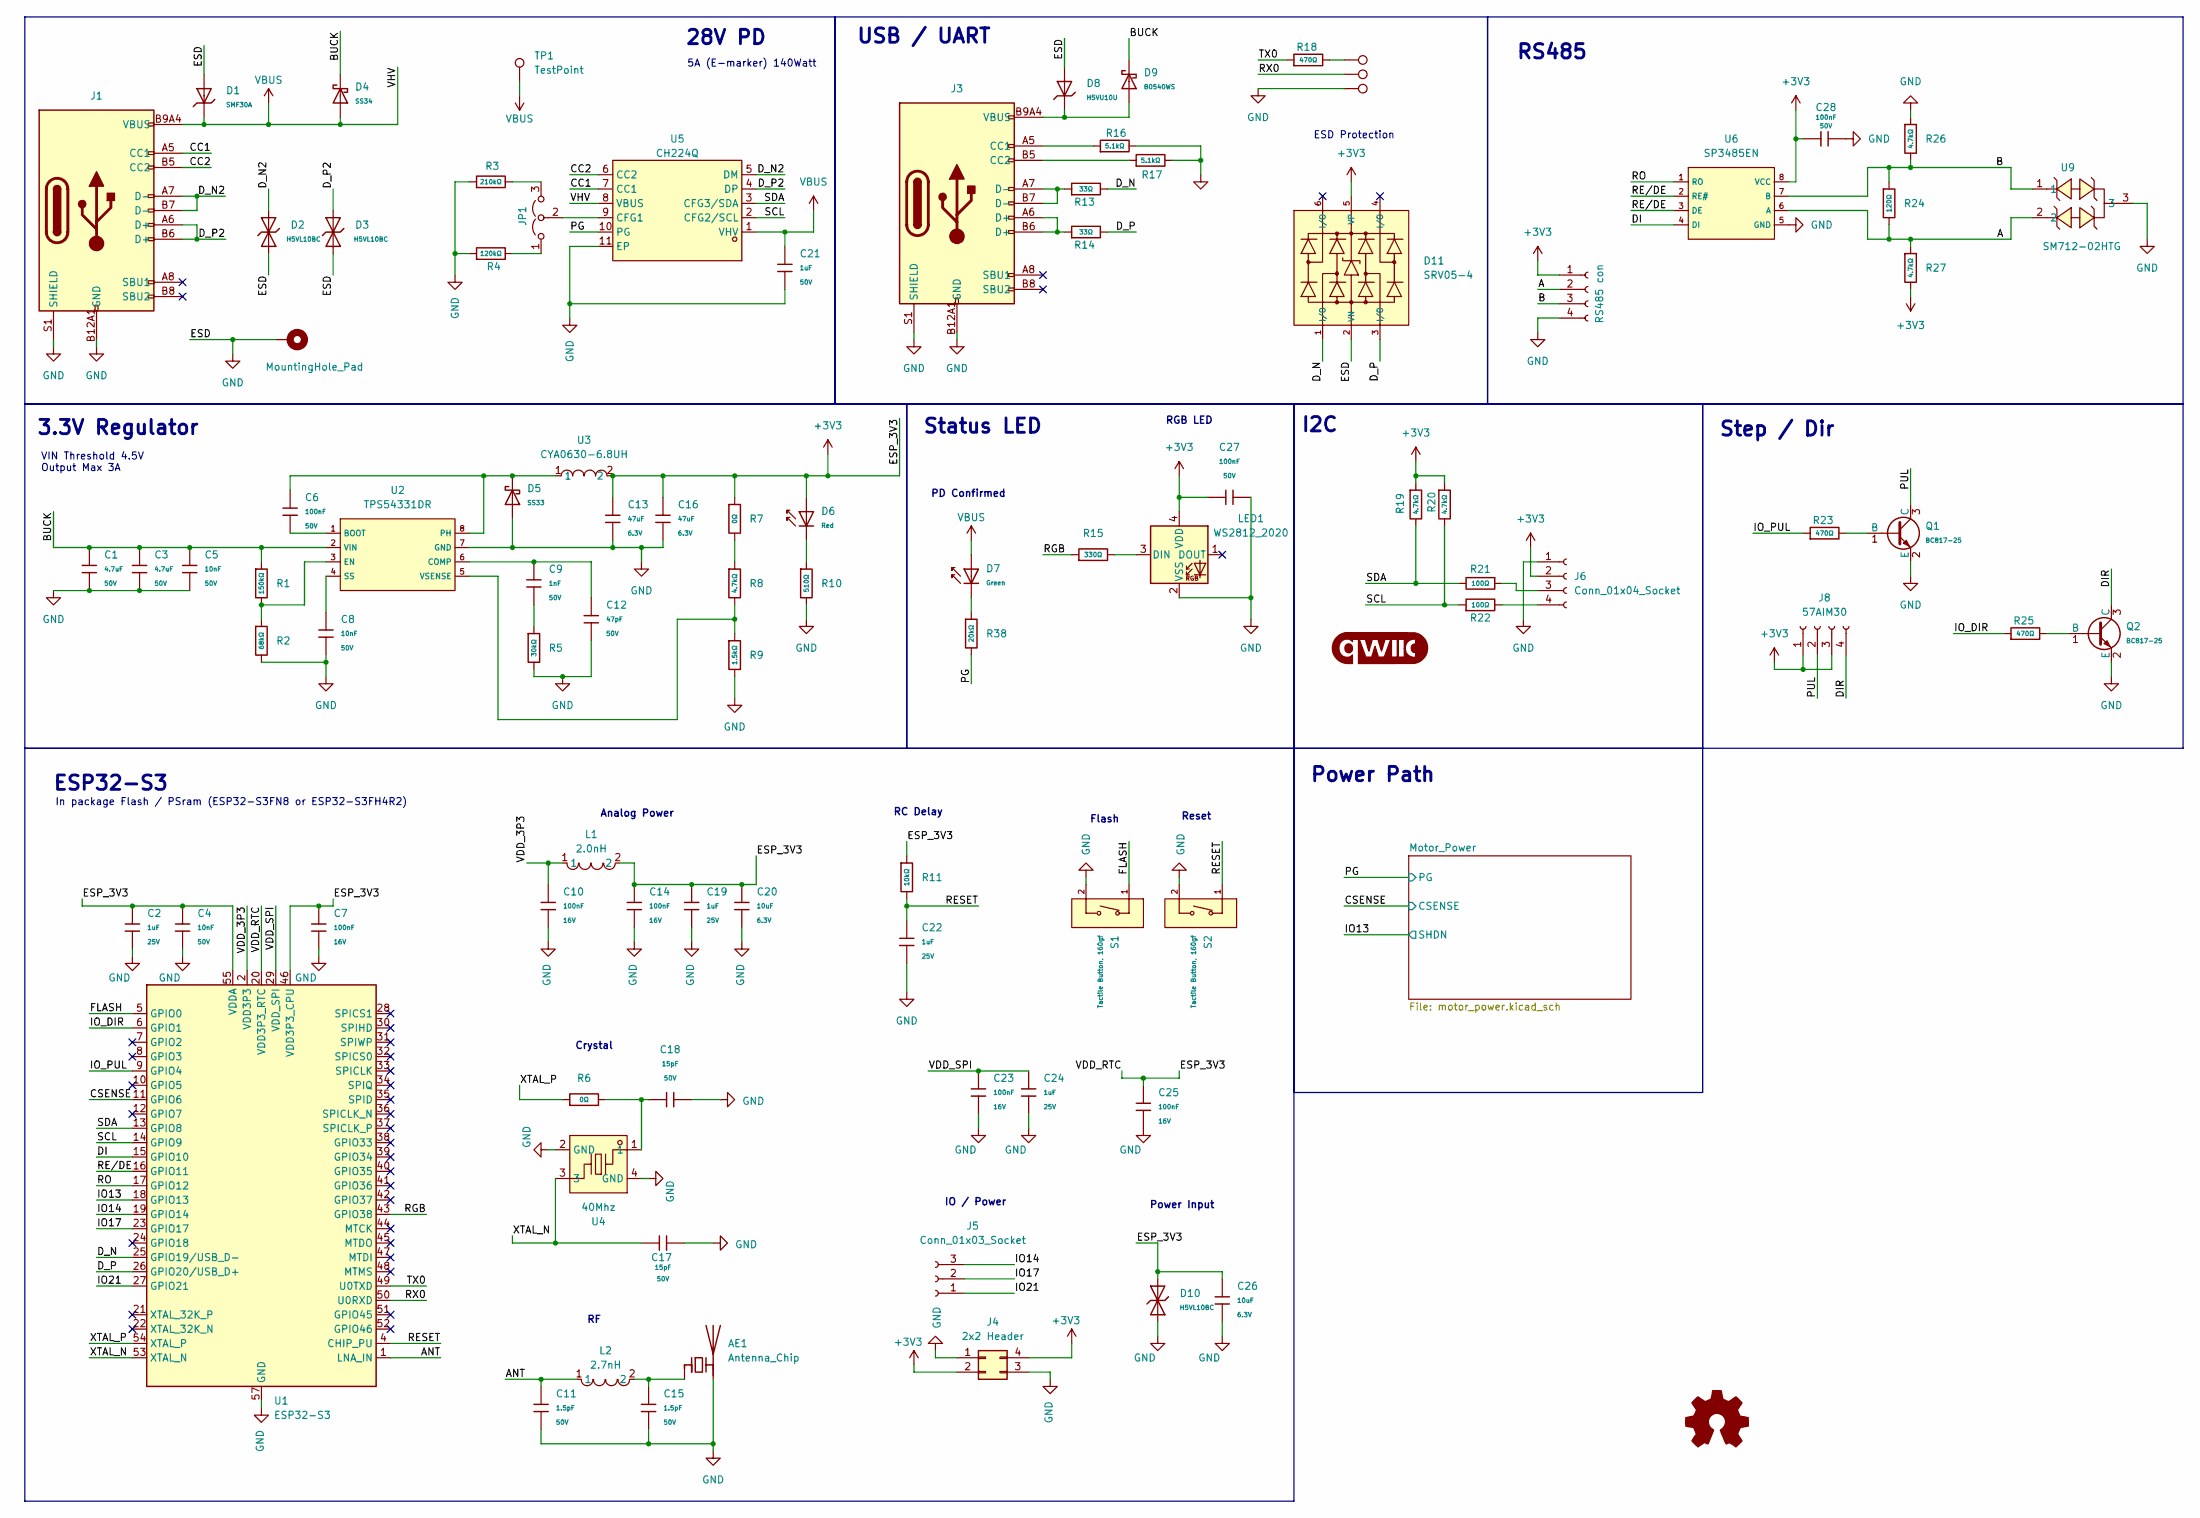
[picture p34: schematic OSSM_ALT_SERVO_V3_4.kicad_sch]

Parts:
AE1: Antenna_Chip; Texas_SWRA117D_2.4GHz_Left
C1, C3: 4.7uF; C_1206; Voltage Rated 50V; Tolerance ±10%; Part 1206B475K500NT; LCSC C29823
C2, C19, C22, C24: 1uF; C_0402; Voltage Rated 25V; Tolerance ±10%; Part CL05A105KA5NQNC; LCSC C52923
C4, C5, C8: 10nF; C_0402; Voltage Rated 50V; Tolerance ±10%; Part CL05B103KB5NNNC; LCSC C15195
C6, C27, C28: 100nF; C_0402; Voltage Rated 50V; Tolerance ±10%; Part CL05B104KB54PNC; LCSC C307331
C7, C10, C14, C23, C25: 100nF; C_0402; Voltage Rated 16V; Tolerance ±10%; Part CL05B104KO5NNNC; LCSC C1525
C9: 1nF; C_0402; Voltage Rated 50V; Tolerance ±10%; Part 0402B102K500NT; LCSC C1523
C11, C15: 1.5pF; C_0402; Voltage Rated 50V; Part 0402CG1R5C500NT; LCSC C1552
C12: 47pF; C_0402; Voltage Rated 50V; Tolerance ±5%; Part 0402CG470J500NT; LCSC C1567
C13, C16: 47uF; C_0805; Voltage Rated 6.3V; Tolerance ±20%; Part CL21A476MQYNNNE; LCSC C16780
C17, C18: 15pF; C_0402; Voltage Rated 50V; Tolerance ±5%; Part 0402CG150J500NT; LCSC C1548
C20, C26: 10uF; C_0402; Voltage Rated 6.3V; Tolerance ±20%; Part CL05A106MQ5NUNC; LCSC C15525
C21: 1uF; C_0603; Voltage Rated 50V; Tolerance ±10%; Part CL10A105KB8NNNC; LCSC C15849
D1: SMF30A; D_SOD-123FL; Breakdown Voltage 33.3V; Part SMF30A; LCSC C19077518
D2, D3, D10: H5VL10BC; D_DFN1006-2L; Part H5VL10BC; LCSC C20615784
D4: SS34; D_SMA; Forward Voltage (Vf@If) 550mV@3A; Reverse Voltage (Vr) 40V; Part SS34; LCSC C8678
D5: SS33; D_SMA; Part SS33; LCSC C28646294
D6: Red; D_0603; Part KT-0603R; LCSC C2286
D7: Green; D_0805; Part KT-0805G; LCSC C2297
D8: H5VU10U; D_DFN1006-2L; Breakdown Voltage 9V; Part H5VU10U; LCSC C22395519
D9: B0540WS; D_SOD-323; Part B0540WS; LCSC C7420326
D11: SRV05-4; SOT-23-6_L2.9-W1.6-P0.95-LS2.8-BL-1; Breakdown Voltage (Vbr) 6V; Clamping Voltage@Ipp 12.5V; Part SRV05-4; LCSC C7420376
G1: qwiic_Logo; qwiic_3mm
H1: MountingHole_Pad; MountingHole_3.2mm_M3_Pad
J1, J3: Connector, USB-TYPE-C-16P; TYPE-C-SMD_HX-TYPE-C-16PIN; LCSC C2927039
J4: 2x2 Header; PinHeader_2x02_P2.54mm_Vertical
J5: Conn_01x03_Socket; PinHeader_1x03_P2.54mm_Vertical
J6: Conn_01x04_Socket; JST_SH_SM04B-SRSS-TB_1x04-1MP_P1.00mm_Horizontal; LCSC C51940130
J7: RS485 con; OSSM ALT RS485 Connector
J8: 57AIM30; JST_PH_B4B-PH-K_1x04_P2.00mm_Vertical
JP1: Jumper_3_Open; PinHeader_1x03_P2.54mm_Vertical
L1: 2.0nH; L0402; LCSC Part C18216
L2: 2.7nH; L0402; LCSC C778766
LED1: WS2812_2020; LED_WS2812_2020; LCSC C42417600
Q1, Q2: BC817-25; Q_SOT-23; Part BC817-25; LCSC C20069154
R1: 150kΩ; R_0402; Overload Voltage (Max) 75V; Tolerance ±1%; Part 0603WAF1503T5E; LCSC C25755
R2: 68kΩ; R_0402; Overload Voltage (Max) 75V; Tolerance ±1%; Part 0603WAF6802T5E; LCSC C36871
R3: 210kΩ; R_0603; Overload Voltage (Max) 75V; Tolerance ±1%; Part 0603WAF2203T5E; LCSC C22952
R4: 120kΩ; R_0603; Overload Voltage (Max) 75V; Tolerance ±1%; Part 0603WAF1203T5E; LCSC C25808
R5: 30kΩ; R_0402; Overload Voltage (Max) 75V; Tolerance ±1%; Part 0603WAF3002T5E; LCSC C25553
R6, R7: 0Ω; R_0402; Overload Voltage (Max) 50V; Tolerance ±1%; Part 0402WGF0000TCE; LCSC C17168
R8, R19, R20, R26, R27: 4.7kΩ; R_0402; Overload Voltage (Max) 50V; Tolerance ±1%; Part 0402WGF4701TCE; LCSC C25900
R9: 1.5kΩ; R_0402; Overload Voltage (Max) 50V; Tolerance ±1%; Part 0402WGF1501TCE; LCSC C25867
R10: 510Ω; R_0603; Overload Voltage (Max) 75V; Tolerance ±1%; Part 0603WAF5100T5E; LCSC C23193
R11: 10kΩ; R_0402; Overload Voltage (Max) 50V; Tolerance ±1%; Part 0402WGF1002TCE; LCSC C25744
R13, R14: 33Ω; R_0402; Overload Voltage (Max) 50V; Tolerance ±1%; Part 0402WGF330JTCE; LCSC C25105
R15: 330Ω; R_0402; Overload Voltage (Max) 50V; Tolerance ±1%; Part 0402WGF3300TCE; LCSC C25104
R16, R17: 5.1kΩ; R_0402; Overload Voltage (Max) 50V; Tolerance ±1%; Part 0402WGF5101TCE; LCSC C25905
R18, R23, R25: 470Ω; R_0402; Overload Voltage (Max) 50V; Tolerance ±1%; Part 0402WGF4700TCE; LCSC C25117
R21, R22: 100Ω; R_0402; Overload Voltage (Max) 50V; Tolerance ±1%; Part 0402WGF1000TCE; LCSC C25076
R24: 120Ω; R_0603; Overload Voltage (Max) 75V; Tolerance ±1%; Part 0603WAF1200T5E; LCSC C22787
R38: 20kΩ; R_0603; Overload Voltage (Max) 75V; Tolerance ±1%; Part 0603WAF2002T5E; LCSC C4184
S1, S2: Tactile Button, 160gf; SW_TS-1088-AR02016; Voltage Rating (Dc) 12V; Part TS-1088-AR02016; LCSC C720477
TP1: TestPoint; TestPoint_Pad_D1.0mm
TP2, TP3, TP4: TestPoint; TestPoint_Pad_D1.5mm
U1: ESP32-S3; QFN-56-1EP_7x7mm_P0.4mm_EP4x4mm_ThermalVias; LCSC C2913196
U2: TPS54331DR; SOIC-8_L5.0-W4.0-P1.27-LS6.0-BL; Output Voltage 0.8V~25V; Input Voltage 3.5V~28V; Part TPS54331DR; LCSC C9865
U3: CYA0630-6.8UH; IND-SMD_L7.2-W6.6_GPSR0730; LCSC Part C5189749
U4: 40Mhz; ESP32 40Mhz Crystal C7206306; LCSC Part C7206306
U5: CH224Q; SON-10_L2.0-W2.0-P0.40-TL-EP; LCSC Part C46061833
U6: SP3485EN; SOIC-8_L5.0-W4.0-P1.27-LS6.0-BL; Supply Voltage 3.3V; Part SP3485EN-L/TR; LCSC C8963
U9: SM712-02HTG; SOT-23-3_L2.9-W1.3-P1.90-LS2.4-BR; LCSC Part C5449363

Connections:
+3V3: C2.1, C4.1, C7.2, C13.1, C14.1, C16.1, C19.1, C20.1, C25.2, C26.2, C27.2, C28.1, D6.2, D10.2, D11.5 (VP), J4.2, J4.4, J6.2, J7.1, J8.1, J8.3, L1.2, LED1.4 (VDD), R7.1, R11.1, R19.1, R20.1, R27.2, U1.20 (VDD3P3_RTC), U1.46 (VDD3P3_CPU), U1.55 (VDDA), U1.56 (VDDA), U3.2, U6.8 (VCC); also elsewhere on the board
/A: J7.2, R24.2, R27.1, U6.6 (A), U9.2
/ANT: C11.1, L2.1, U1.1 (LNA_IN)
/B: J7.3, R24.1, R26.2, U6.7 (B), U9.1
/BUCK: C1.1, C3.1, C5.1, D4.1, D9.1, R1.1, U2.2 (VIN)
/CC1: J1.A5 (CC1), U5.7 (CC1)
/CC2: J1.B5 (CC2), U5.6 (CC2)
/CSENSE: U1.11 (GPIO6); also elsewhere on the board
/DI: U1.15 (GPIO10), U6.4 (DI)
/DIR: J8.4, Q2.3 (C)
/D_N: D11.1 (I/O), R13.2, U1.25 (GPIO19/USB_D-)
/D_N2: D2.2, J1.A7 (D-), J1.B7 (D-), U5.5 (DM)
/D_P: D11.3 (I/O), R14.2, U1.26 (GPIO20/USB_D+)
/D_P2: D3.2, J1.A6 (D+), J1.B6 (D+), U5.4 (DP)
/FLASH: S1.1 (A), U1.5 (GPIO0)
/IO13: U1.18 (GPIO13); also elsewhere on the board
/IO14: J5.3, U1.19 (GPIO14)
/IO17: J5.2, U1.23 (GPIO17)
/IO21: J5.1, U1.27 (GPIO21)
/IO_DIR: R25.1, U1.6 (GPIO1)
/IO_PUL: R23.1, U1.9 (GPIO4)
/PG: R38.2, U5.10 (PG); also elsewhere on the board
/PUL: J8.2, Q1.3 (C)
/RESET: C22.1, R11.2, S2.1 (A), U1.4 (CHIP_PU)
/RE/DE: U1.16 (GPIO11), U6.2 (RE#), U6.3 (DE)
/RGB: R15.1, U1.43 (GPIO38)
/RO: U1.17 (GPIO12), U6.1 (RO)
/RX0: TP3.1 (1_1), U1.50 (U0RXD)
/SCL: R20.2, R22.1, U1.14 (GPIO9), U5.2 (CFG2/SCL)
/SDA: R19.2, R21.2, U1.13 (GPIO8), U5.3 (CFG3/SDA)
/TX0: R18.1, U1.49 (U0TXD)
/VDD_3P3: C10.1, L1.1, U1.2 (VDD3P3), U1.3 (VDD3P3)
/VDD_SPI: C23.1, C24.1, U1.29 (VDD_SPI)
/XTAL_N: C17.1, U1.53 (XTAL_N), U4.3
/XTAL_P: R6.1, U1.54 (XTAL_P)
GND: AE1.2 (PCB_Trace), C1.2, C2.2, C3.2, C4.2, C5.2, C7.1, C8.2, C10.2, C11.2, C12.2, C13.2, C14.2, C15.2, C16.2, C17.2, C18.2, C19.2, C20.2, C21.2, C22.2, C23.2, C24.2, C25.1, C26.1, C27.1, C28.2, D1.2, D2.1, D3.1, D5.2, D8.2, D10.1, D11.2 (VN), H1.1 (1_1), J1.A12B1 (GND), J1.B12A1 (GND), J1.S1 (SHIELD), J3.A12B1 (GND), J3.B12A1 (GND), J3.S1 (SHIELD), J4.1, J4.3, J6.1, J7.4, LED1.2 (VSS), Q1.2 (E), Q2.2 (E), R2.2, R3.1, R4.1, R5.2, R9.2, R10.2, R16.2, R17.2, R26.1, S1.2 (B), S2.2 (B), TP4.1 (1_1), U1.57 (GND), U2.7 (GND), U4.2 (GND), U4.4 (GND), U5.11 (EP), U6.5 (GND), U9.3; also elsewhere on the board
unnamed: AE1.1 (FEED), C15.1, L2.2
unnamed: C9.2, R5.1
unnamed: C18.1, R6.2, U4.1
unnamed: D6.1, R10.1
unnamed: D7.1, R38.1
unnamed: D8.1, D9.2, J3.A9B4 (VBUS), J3.B9A4 (VBUS)
unnamed: J3.A5 (CC1), R16.1
unnamed: J3.B5 (CC2), R17.1
unnamed: J3.A6 (D+), J3.B6 (D+), R14.1
unnamed: J3.A7 (D-), J3.B7 (D-), R13.1
unnamed: J6.3, R21.1
unnamed: J6.4, R22.2
unnamed: JP1.1 (A), R4.2
unnamed: JP1.3 (B), R3.2
unnamed: JP1.2 (C), U5.9 (CFG1)
unnamed: LED1.3 (DIN), R15.2
unnamed: Q1.1 (B), R23.2
unnamed: Q2.1 (B), R25.2
unnamed: R7.2, R8.1
unnamed: R18.2, TP2.1 (1_1)
unnamed: C6.2, U2.1 (BOOT)
unnamed: C9.1, C12.1, U2.6 (COMP)
unnamed: R1.2, R2.1, U2.3 (EN)
unnamed: C6.1, D5.1, U2.8 (PH), U3.1
unnamed: C8.1, U2.4 (SS)
unnamed: R8.2, R9.1, U2.5 (VSENSE)
VBUS: C21.1, D1.1, D4.2, D7.2, J1.A9B4 (VBUS), J1.B9A4 (VBUS), TP1.1 (1_1), U5.1 (VHV), U5.8 (VBUS); also elsewhere on the board

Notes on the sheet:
ESD Protection
IO / Power
In package Flash / PSram (ESP32-S3FN8 or ESP32-S3FH4R2)
Reset
Analog Power
RGB LED
5A (E-marker) 140Watt
Step / Dir
Status LED
PD Confirmed
28V PD
VIN Threshold 4.5V Output Max 3A
Power Path
RC Delay
USB / UART
3.3V Regulator
RS485
Flash
Power Input
Crystal
I2C
ESP32-S3

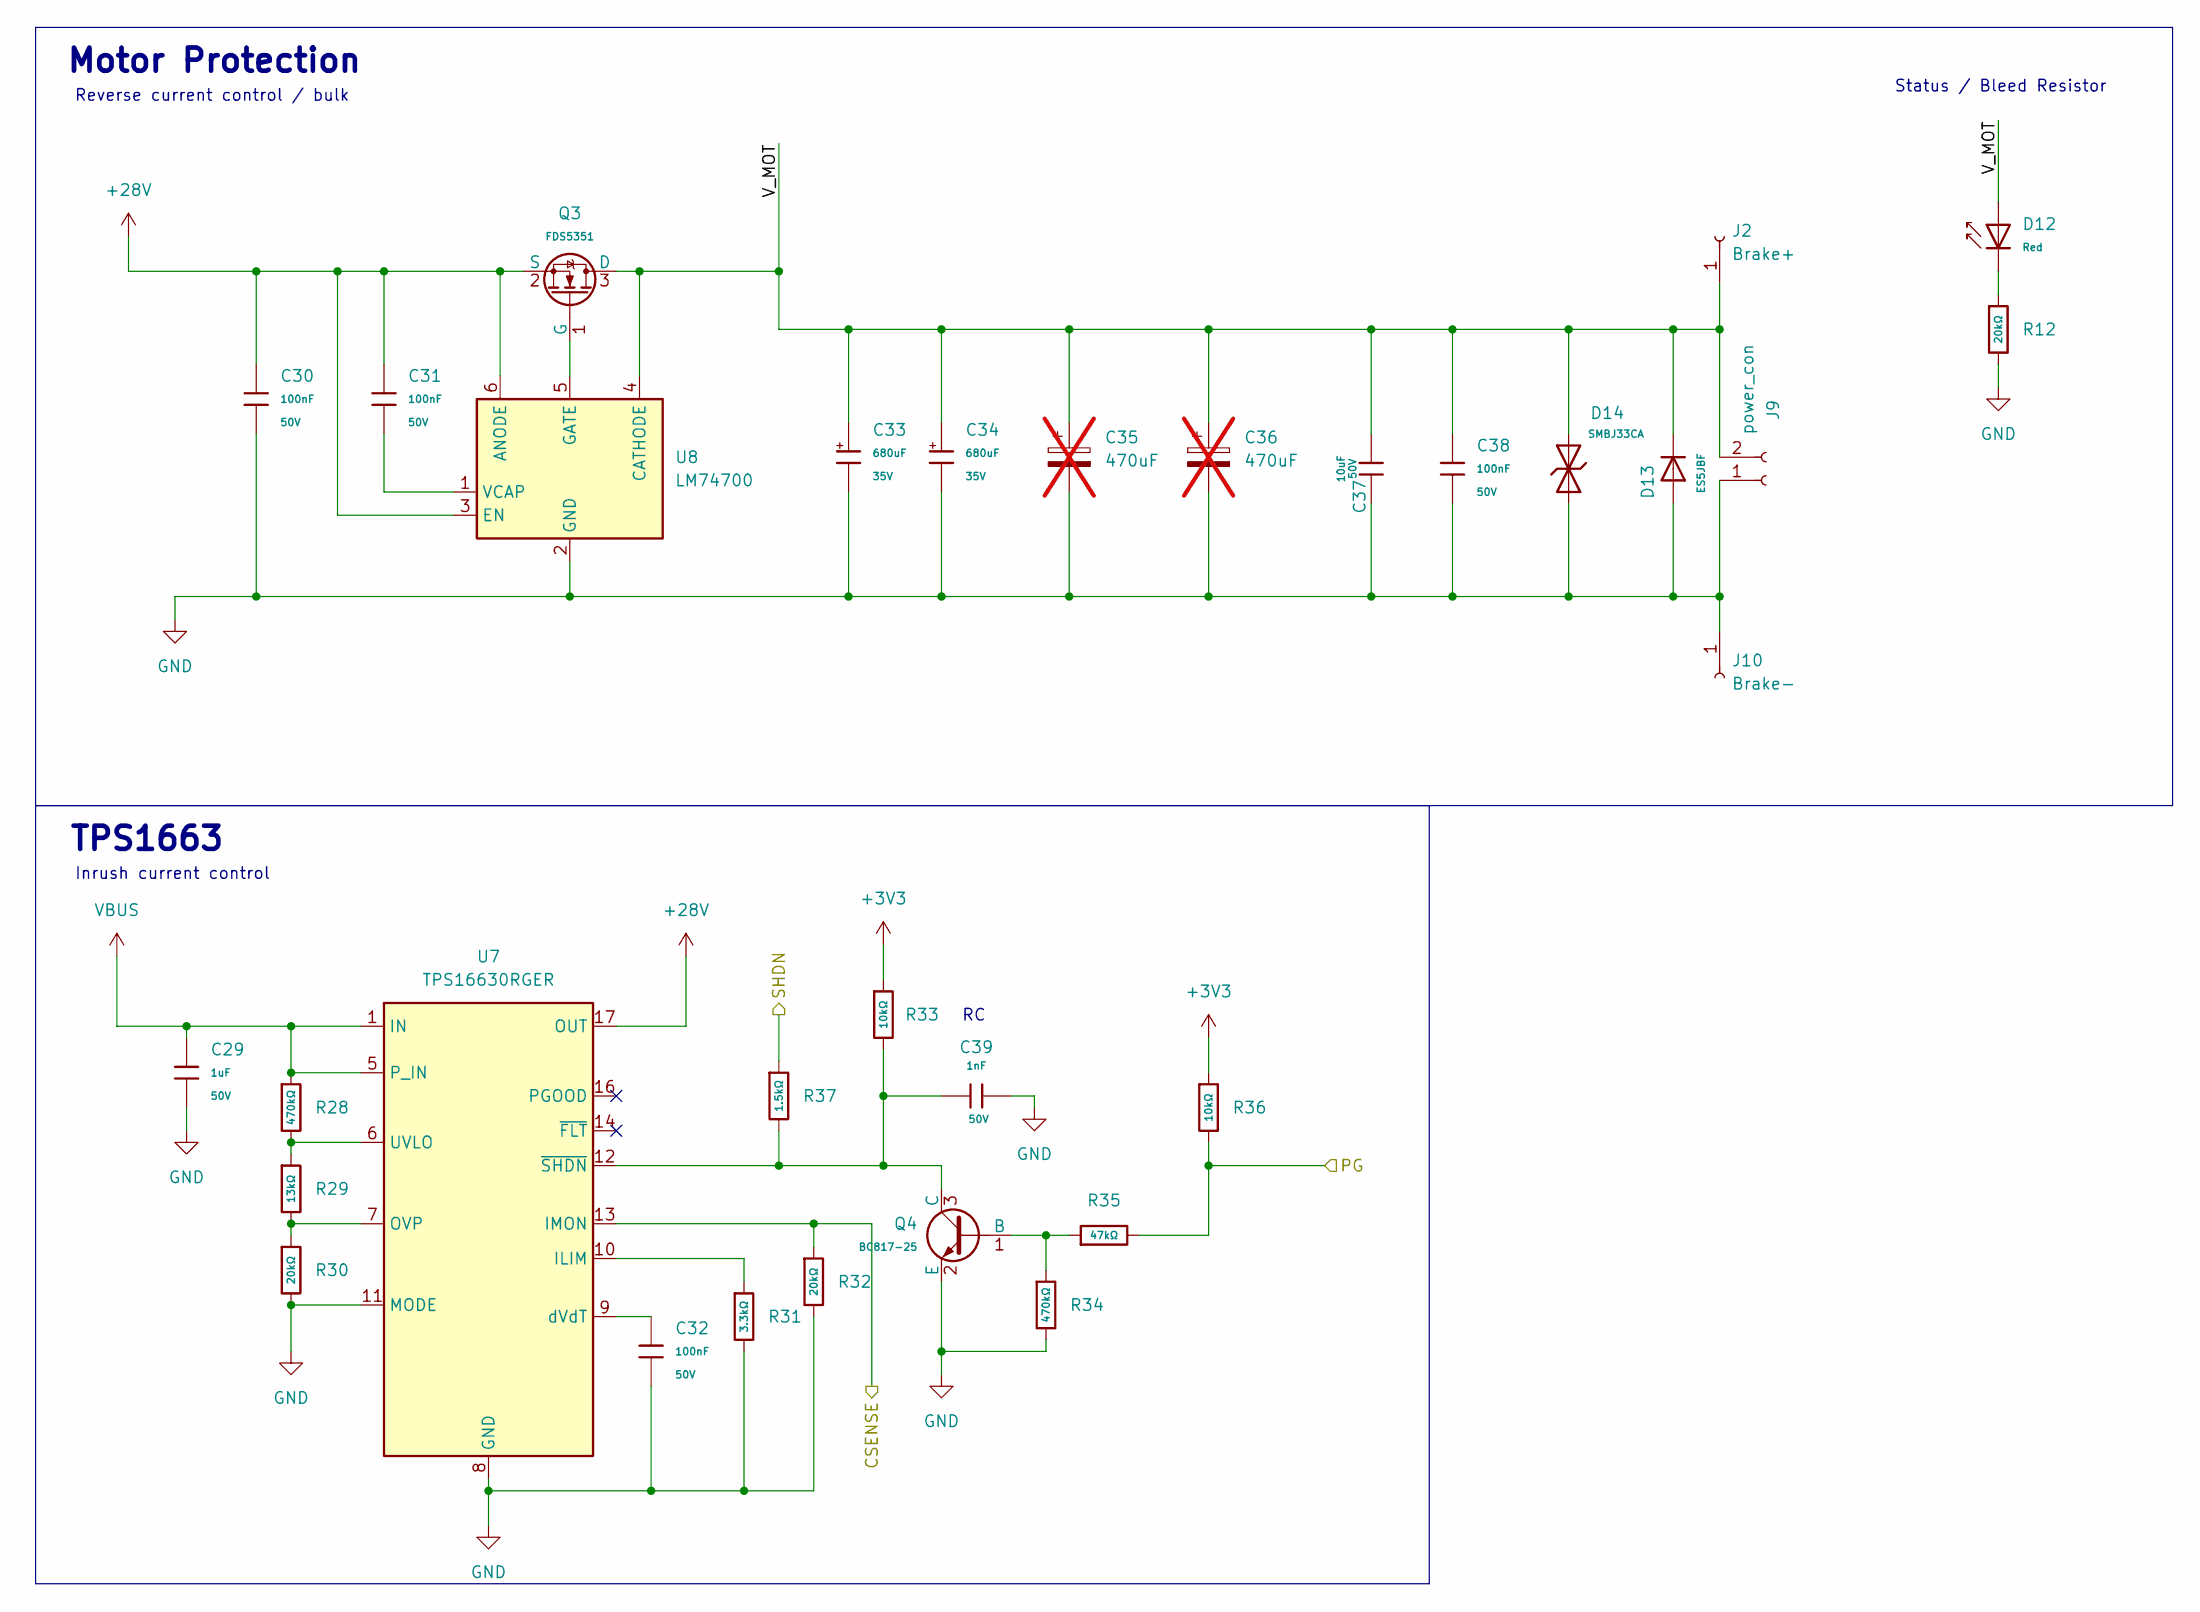
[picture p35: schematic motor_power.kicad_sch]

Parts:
C29: 1uF; C_0603; Voltage Rated 50V; Tolerance ±10%; Part CL10A105KB8NNNC; LCSC C15849
C30, C31, C32, C38: 100nF; C_0603; Voltage Rated 50V; Tolerance ±10%; Part CC0603KRX7R9BB104; LCSC C14663
C33, C34: 680uF; CAP-SMD_BD10.0-L10.3-W10.3-LS11.3-FD; Tolerance ±10%; Rated Voltage 35V; Part TAJA106K016RNJ; LCSC C46643177
C35, C36: 470uF; CP_Radial_D10.0mm_P5.00mm_P7.50mm; not fitted
C37: 10uF; C_1206; Voltage Rated 50V; Tolerance ±10%; Part CL31A106KBHNNNE; LCSC C13585
C39: 1nF; C_0402; Voltage Rated 50V; Tolerance ±10%; Part 0402B102K500NT; LCSC C1523
D12: Red; D_0603; Part KT-0603R; LCSC C2286
D13: ES5JBF; D_SMBF; Part ES5JBF; LCSC C18199154
D14: SMBJ33CA; D_SMB; Part SMBJ33CA; LCSC C19077587
J2: Brake+; SolderWirePad_1x01_SMD_3x6mm
J9: power_con; TerminalBlock_Phoenix_MKDS-1,5-2-5.08_1x02_P5.08mm_Horizont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
J10: Brake-; SolderWirePad_1x01_SMD_3x6mm
Q3: FDS5351; SO-8 N-channel mosfet FDS5351; Part 2N7002; LCSC C241809
Q4: BC817-25; Q_SOT-23; Part BC817-25; LCSC C20069154
R12, R30, R32: 20kΩ; R_0603; Overload Voltage (Max) 75V; Tolerance ±1%; Part 0603WAF2002T5E; LCSC C4184
R28, R34: 470kΩ; R_0603; Overload Voltage (Max) 75V; Tolerance ±1%; Part 0603WAF4703T5E; LCSC C23178
R29: 13kΩ; R_0603; Overload Voltage (Max) 75V; Tolerance ±1%; Part 0603WAF1302T5E; LCSC C22797
R31: 3.3kΩ; R_0603; Overload Voltage (Max) 75V; Tolerance ±1%; Part 0603WAF3301T5E; LCSC C22978
R33, R36: 10kΩ; R_0603; Overload Voltage (Max) 75V; Tolerance ±1%; Part 0603WAF1002T5E; LCSC C25804
R35: 47kΩ; R_0603; Overload Voltage (Max) 75V; Tolerance ±1%; Part 0603WAF4702T5E; LCSC C25819
R37: 1.5kΩ; R_0402; Overload Voltage (Max) 50V; Tolerance ±1%; Part 0402WGF1501TCE; LCSC C25867
U7: TPS16630RGER; VQFN-24-1EP_4x4mm_P0.5mm_EP2.5x2.5mm_ThermalVias; LCSC C1850279
U8: LM74700; SOT-23-6; LCSC C2941042

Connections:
+3V3: R33.1, R36.1; also elsewhere on the board
+28V: C30.1, C31.1, Q3.2 (S), U7.17 (OUT), U7.18 (OUT), U8.3 (EN), U8.6 (ANODE)
/CSENSE: R32.1, U7.13 (IMON); also elsewhere on the board
/IO13: R37.1; also elsewhere on the board
/Motor_Power/V_MOT: C33.1, C34.1, C35.1, C36.1, C37.1, C38.1, D12.2, D13.1, D14.2, J2.1 (Pin_1_1), J9.2, Q3.3 (D), U8.4 (CATHODE)
/PG: R35.2, R36.2; also elsewhere on the board
GND: C29.2, C30.2, C32.2, C33.2, C34.2, C35.2, C36.2, C37.2, C38.2, C39.2, D13.2, D14.1, J9.1, J10.1 (Pin_1_1), Q4.2 (E), R12.2, R30.2, R31.2, R32.2, R34.2, U7.8 (GND), U7.11 (MODE), U7.25 (GND), U8.2 (GND); also elsewhere on the board
unnamed: D12.1, R12.1
unnamed: Q3.1 (G), U8.5 (GATE)
unnamed: Q4.1 (B), R34.1, R35.1
unnamed: C39.1, Q4.3 (C), R33.2, R37.2, U7.12 (~SHDN)
unnamed: R31.1, U7.10 (ILIM)
unnamed: R29.2, R30.1, U7.7 (OVP)
unnamed: R28.2, R29.1, U7.6 (UVLO)
unnamed: C32.1, U7.9 (dVdT)
unnamed: C31.2, U8.1 (VCAP)
VBUS: C29.1, R28.1, U7.1 (IN), U7.2 (IN), U7.5 (P_IN); also elsewhere on the board

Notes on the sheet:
TPS1663
Reverse current control / bulk
Inrush current control
Motor Protection
Status / Bleed Resistor

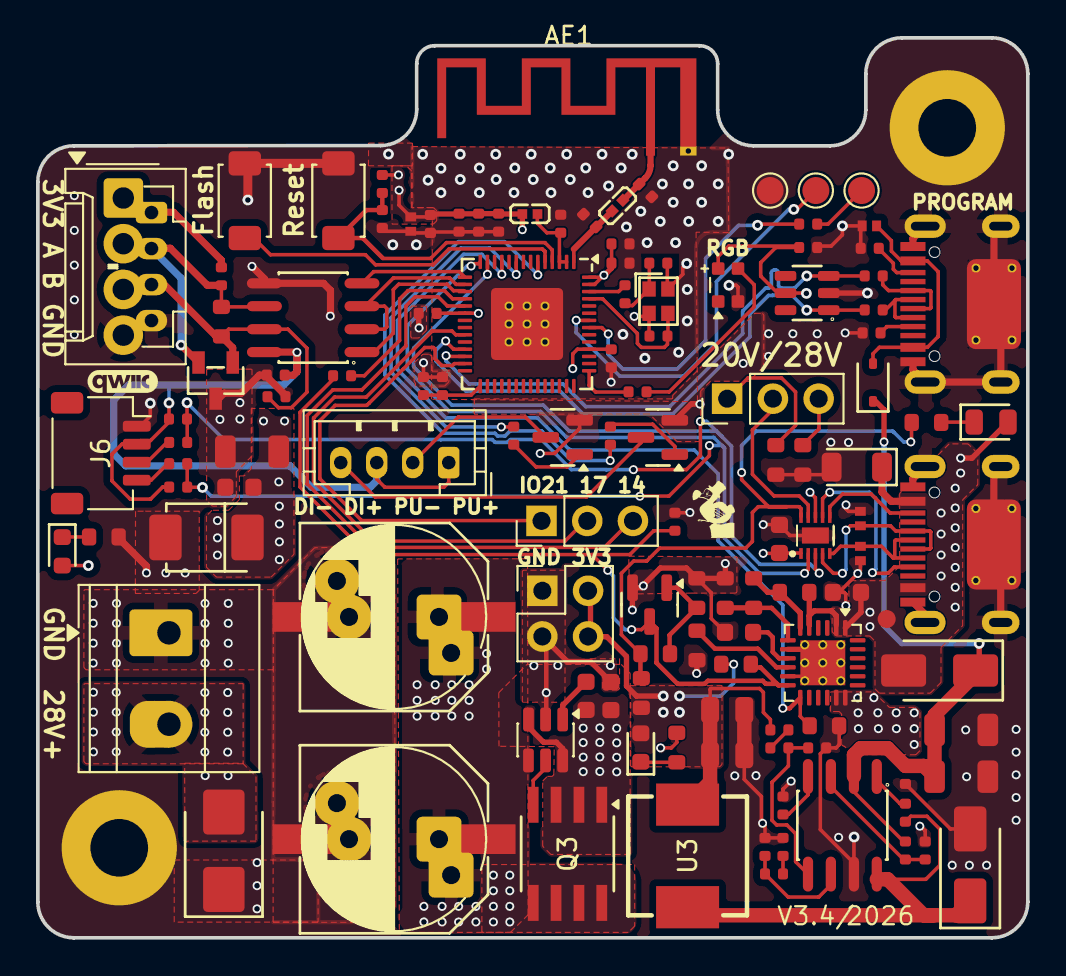
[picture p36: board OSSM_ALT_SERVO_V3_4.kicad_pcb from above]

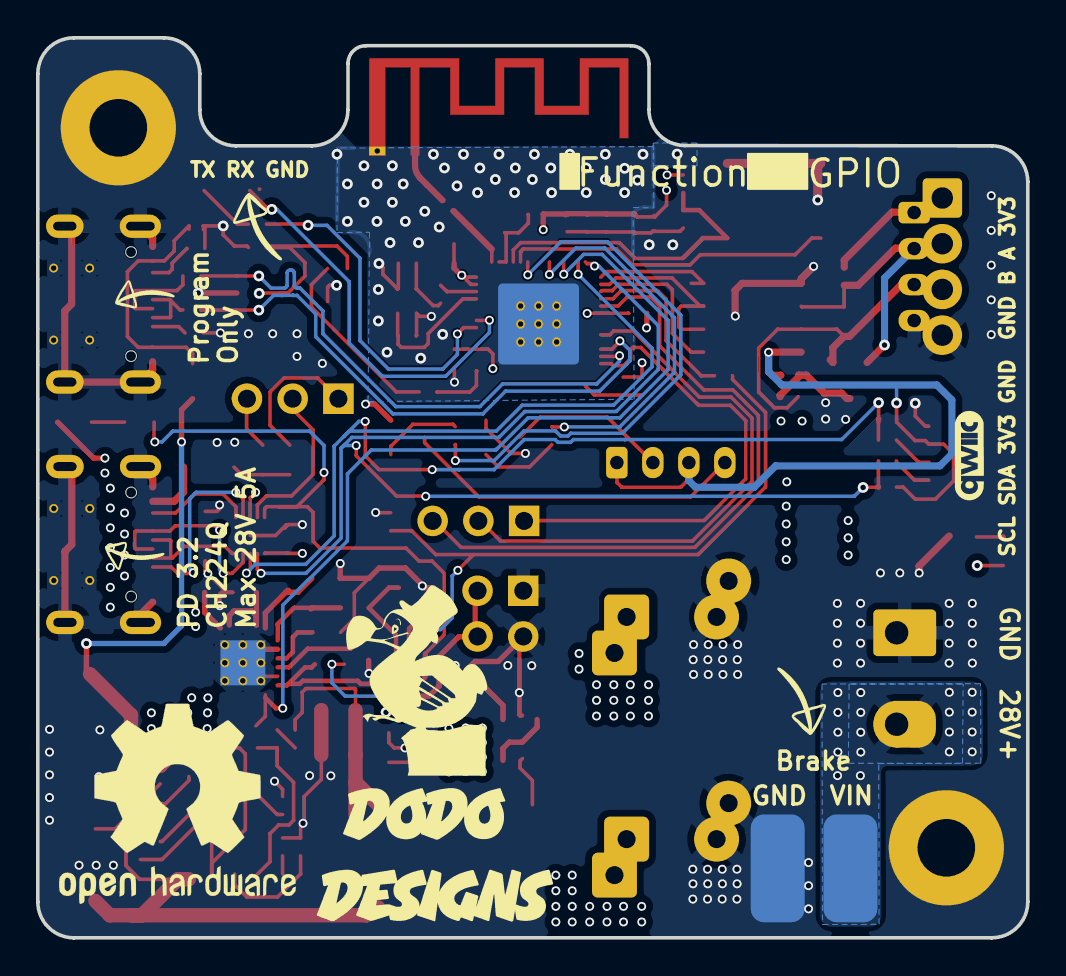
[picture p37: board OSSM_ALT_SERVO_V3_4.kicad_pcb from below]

Board: 4 copper layers, 55.0 x 50.0 mm, 128 parts (3 on the bottom side), 74 nets.

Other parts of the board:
MountingHole: (no value)
OSHWLOGO: OSHW-Logo2_14.6x12mm_SilkScreen

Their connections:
GND: MountingHole.1; also elsewhere on the board

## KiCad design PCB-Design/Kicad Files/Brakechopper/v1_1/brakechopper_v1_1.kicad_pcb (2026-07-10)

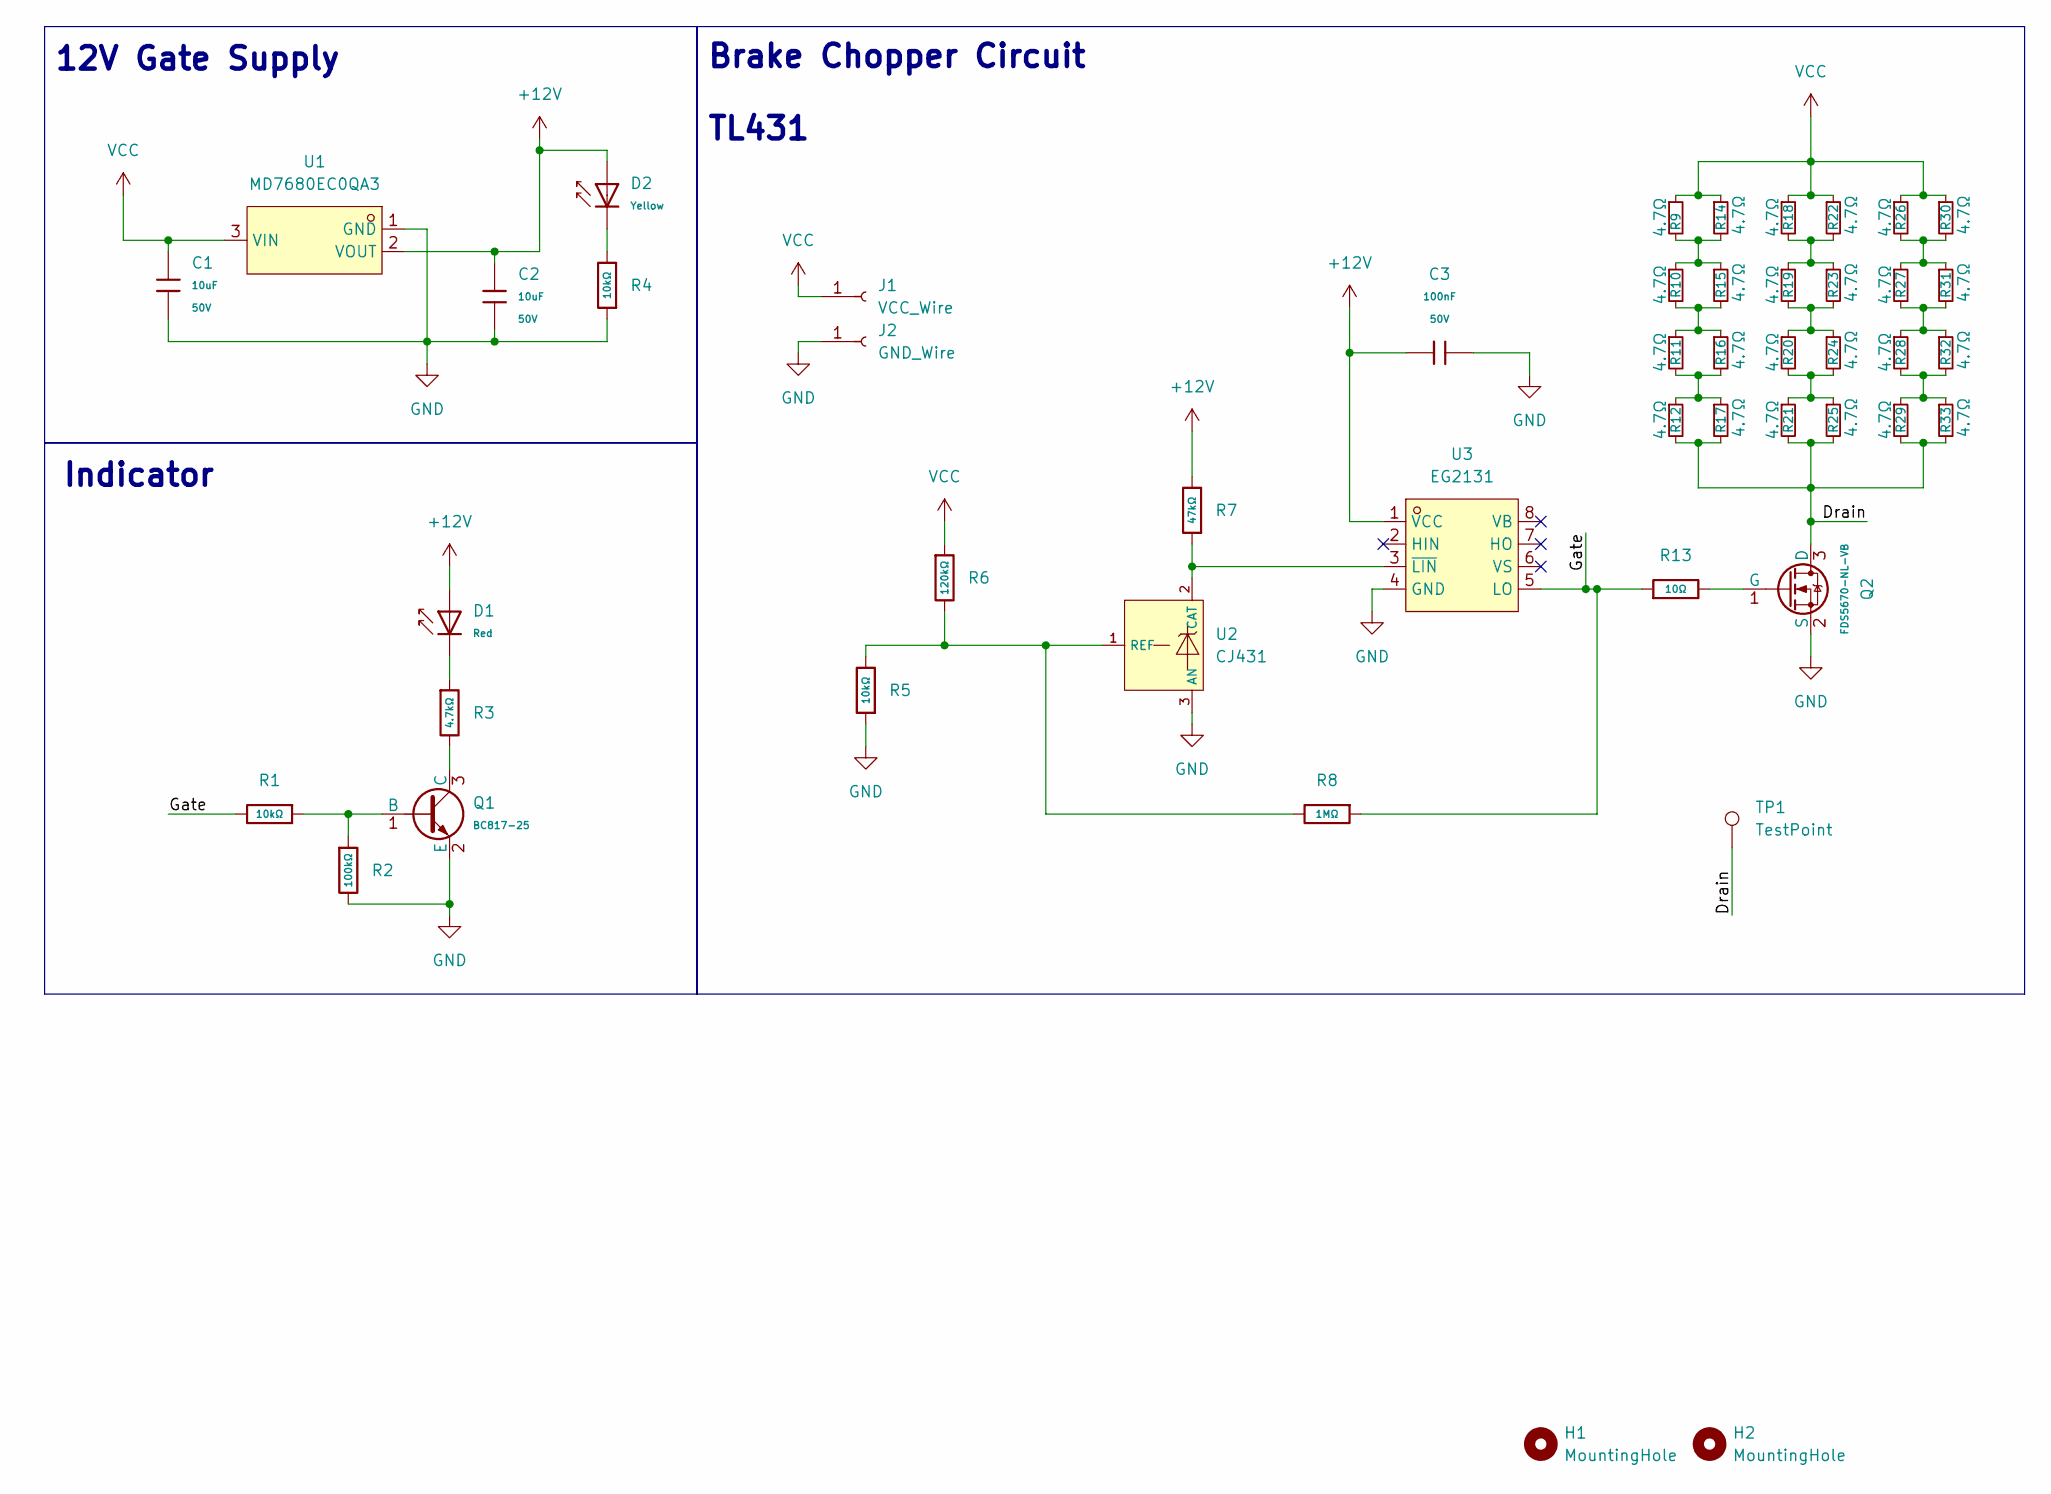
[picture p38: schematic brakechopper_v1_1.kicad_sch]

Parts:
C1, C2: 10uF; C_0805; Voltage Rated 50V; Tolerance ±10%; Part GRM21BR61H106KE43L; LCSC C440198
C3: 100nF; C_0603; Voltage Rated 50V; Tolerance ±10%; Part CC0603KRX7R9BB104; LCSC C14663
D1: Red; D_0603; Part KT-0603R; LCSC C2286
D2: Yellow; D_0603; Forward Voltage (VF) 1.6V~2.6V; Part NCD0603Y2; LCSC C89811
H1, H2: MountingHole; MountingHole_2.2mm_M2_ISO14580
J1: VCC_Wire; Solder_Wire_PowerPort_VCC
J2: GND_Wire; Solder_Wire_PowerPort_GND
Q1: BC817-25; Q_SOT-23; Part BC817-25; LCSC C20069154
Q2: FDS5670-NL-VB; SO-8 N-channel mosfet FDS5351; Part 2N7002; LCSC C5878792
R1, R4, R5: 10kΩ; R_0603; Overload Voltage (Max) 75V; Tolerance ±1%; Part 0603WAF1002T5E; LCSC C25804
R2: 100kΩ; R_0603; Overload Voltage (Max) 75V; Tolerance ±1%; Part 0603WAF1003T5E; LCSC C25803
R3: 4.7kΩ; R_0603; Overload Voltage (Max) 75V; Tolerance ±1%; Part 0603WAF4701T5E; LCSC C23162
R6: 120kΩ; R_0603; Overload Voltage (Max) 75V; Tolerance ±1%; Part 0603WAF1203T5E; LCSC C25808
R7: 47kΩ; R_0603; Overload Voltage (Max) 75V; Tolerance ±1%; Part 0603WAF4702T5E; LCSC C25819
R8: 1MΩ; R_0603; Overload Voltage (Max) 75V; Tolerance ±1%; Part 0603WAF1004T5E; LCSC C22935
R9, R10, R11, R12, R14, R15, R16, R17, R18, R19, R20, R21, R22, R23, R24, R25, R26, R27, R28, R29, R30, R31, R32, R33: 4.7Ω; R_1218_3246Metric_Pad1.22x4.75mm_HandSolder; LCSC C876073
R13: 10Ω; R_0603; Overload Voltage (Max) 75V; Tolerance ±1%; Part 0603WAF100JT5E; LCSC C22859
TP1: TestPoint; TestPoint_Pad_D1.0mm
U1: MD7680EC0QA3; SOT-23-3L_L2.9-W1.6-P1.90-LS2.8-BL; LCSC Part C42377927
U2: CJ431; SOT-23-3_L2.9-W1.6-P1.90-LS2.8-BR; Output Voltage 2.5V~36V; Tolerance ±0.5%; Part CJ431; LCSC C3113
U3: EG2131; SOP-8_L4.9-W3.9-P1.27-LS6.0-BL; LCSC Part C5240691

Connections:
+12V: C2.2, C3.1, D1.2, D2.2, R7.2, U1.2 (VOUT), U3.1 (VCC)
/Drain: Q2.3 (D), R12.2, R17.2, R21.2, R25.2, R29.2, R33.2, TP1.1 (1_1)
/Gate: R1.2, R8.1, R13.1, U3.5 (LO)
GND: C1.1, C2.1, C3.2, J2.1 (Pin_1_1), Q1.2 (E), Q2.2 (S), R2.2, R4.1, R5.1, U1.1 (GND), U2.3 (AN), U3.4 (GND)
unnamed: D1.1, R3.1
unnamed: D2.1, R4.2
unnamed: Q1.1 (B), R1.1, R2.1
unnamed: Q1.3 (C), R3.2
unnamed: Q2.1 (G), R13.2
unnamed: R9.2, R10.1, R14.2, R15.1
unnamed: R10.2, R11.1, R15.2, R16.1
unnamed: R11.2, R12.1, R16.2, R17.1
unnamed: R18.2, R19.1, R22.2, R23.1
unnamed: R19.2, R20.1, R23.2, R24.1
unnamed: R20.2, R21.1, R24.2, R25.1
unnamed: R26.2, R27.1, R30.2, R31.1
unnamed: R27.2, R28.1, R31.2, R32.1
unnamed: R28.2, R29.1, R32.2, R33.1
unnamed: R7.1, U2.2 (CAT), U3.3 (~LIN)
unnamed: R5.2, R6.2, R8.2, U2.1 (REF)
VCC: C1.2, J1.1 (Pin_1_1), R6.1, R9.1, R14.1, R18.1, R22.1, R26.1, R30.1, U1.3 (VIN)

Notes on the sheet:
Indicator
Brake Chopper Circuit TL431
12V Gate Supply

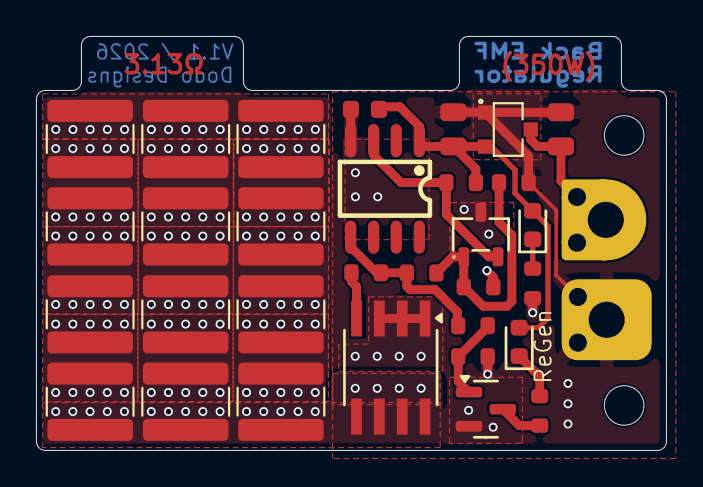
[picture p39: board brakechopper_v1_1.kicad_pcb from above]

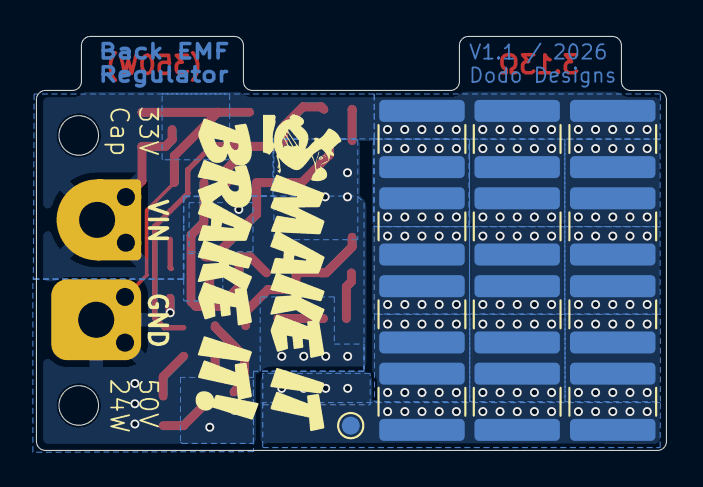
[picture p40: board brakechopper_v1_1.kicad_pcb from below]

Board: 2 copper layers, 35.0 x 23.0 mm, 48 parts (13 on the bottom side), 21 nets.

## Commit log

2025-12-11 Fixed Tolerances after testing with different printers
    [Belt Mechanics - Front - Multicolor.3mf, Belt Mechanics - Front - Single Color.stl, Belt Mechanics - Front - Single.stl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]
2025-12-16 power information
2025-12-16 bom update
    [BOM OSSM ALT.csv]
2025-12-16 fixed links
    [BOM-OSSM-ALT.csv, Belt Clamp (x2).stl, Belt Mechanics - Front - Multicolor.3mf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]
2025-12-16 remove folder
    [BOM OSSM ALT.csv]
2025-12-22 MGN12 Mounts / assembly
    [Belt Clamp (x2).stl, Belt Clamp.step, Belt Mechanics - Front - Multicolor.3mf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]
2026-01-11 Version 1 Print Release
    [Belt Clamp (x2).stl, Belt Mechanics - Front - Multicolor.3mf, Belt Mechanics - Front - Single - Nobranding.stl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]
2026-01-11 PCB folder info
2026-03-09 release 0.9
    [Belt Clamp (x2).stl, Belt Mechanics - Front - Multicolor.3mf, Belt Mechanics - Front - Single - Nobranding.stl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]
2026-03-16 minor tolerance fix
    [Motor Mount - Main Clamp.stl, Motor Mount - Spacer Ring.step]
2026-04-04 updated power adapters
    updated list
2026-04-04 Updated Power List
    Added Apple 67W adapter.
2026-07-10 Added PCB production files, ordering manual and KiCad projects
    [BOM-OSSM-ALT.csv, BOM-OSSM_ALT_SERVO_V3_4.csv, BOM-brakechopper_v1_1.csv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]
2026-07-13 Added missing motor_power sub-sheet and ignore KiCad working files
    [motor_power.kicad_sch]
